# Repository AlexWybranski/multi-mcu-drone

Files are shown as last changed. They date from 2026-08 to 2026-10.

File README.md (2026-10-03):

# multi-mcu-drone

#### Disclaimer
- Due to free profiles of HICPP and CPPCOREGUIDELINES in clang-tidy, this code is supposed to be taken as "HICPP-ish verified"
- **Current State:** Firmware for the STM32 board is tested (all that has been written to this day (**3 Oct 2026**)), work slowed down due to hardware limits - started working on custom pcb

## System overview
This firmware is written primarily in C++. The breakdown of the software modules for each specific board is detailed below:

- [esp32c6-rc](esp32c6-rc/) - Remote control module; handles gamepad input and transmits data wirelessly to the drone via the ESP-NOW protocol.
- [esp32c3-receiver](esp32c3-receiver/) - Receiver module; captures ESP-NOW packets, forwards them to the [stm32f4-main](stm32f4-main/) module via UART, and generates PWM signals for camera servo control.
- [esp32s3-cam](esp32s3-cam/) - Camera module; not implemented at this stage of development.
- [stm32f4-main](stm32f4-main/) - Main flight controller; serves as the brain of the drone, calculating PWM duty cycles for the motors based on UART RX data, accelerometer, and gyroscope inputs.

## Data flow
```mermaid
flowchart LR
%%{init: { 'flowchart': { 'curve': 'stepAfter' }, 'themeCSS': '.edgePath .path { stroke-linejoin: miter; stroke-linecap: square; }' } }%%
    A[Remote Control] 
    B[RECEIVER]
    C[FLIGHT CONTROLLER]
    D[SENSOR]
    E[ESC]
    F[SERVO]
    G[CAM]
    H[HTTP SERVER - VIDEO STREAM]

    A -.->|ESP-NOW| B
    G -.-> H
    subgraph On Drone
    B -->|UART| C
    B -->|PWM| F ===|PHYSICAL CONNECTION|G
    C <-->|SPI| D
    C -->|PWM| E
    end
```

## Credits
- This project uses **[Bluepad32](https://github.com/ricardoquesada/bluepad32)** and its dependency **[BTStack](https://github.com/bluekitchen/btstack)** more about licensing and conditions in [LICENSE-3RD-PARTY](https://github.com/AlexWybranski/multi-mcu-drone/blob/master/LICENSE-3RD-PARTY.md)

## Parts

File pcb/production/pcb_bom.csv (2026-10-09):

Designator | Footprint | Quantity | Value | LCSC Part #
BEC_5V_OUT1 | PinHeader_2x02_P2.54mm_Vertical_SMD | 1 | ~
C3 | CP_EIA-6032-28_Kemet-C_HandSolder | 1 | BEC_50V_20uF
C4 | 1206 | 1 | SER_16V_10uF
C5 | 1206 | 1 | CAM_16V_10uF
C6 | 1206 | 1 | ESP_16V_10uF
C7 | 1206 | 1 | STM_16V_10uF
D1, D2 | D_SOD-123 | 2 | D_Schottky
JST-SH1 | JST_XH_S8B-XH-A_1x08_P2.50mm_Horizontal | 1 | Conn_01x08_Socket
JST-SH2 | JST_XH_S5B-XH-A_1x05_P2.50mm_Horizontal | 1 | Conn_01x05_Socket
R1, R2 | 0805 | 2 | 330
S1 | imu_footprint | 1 | AdaFruit_LSM6DS3_Symbol
U1 | BlackPill AT32F403ACx WeActStudio | 1 | STM32F411CEU6 - BlackPill
U2 | XIAO-ESP32-C6-DIP | 1 | XIAO-ESP32-C6-SMD

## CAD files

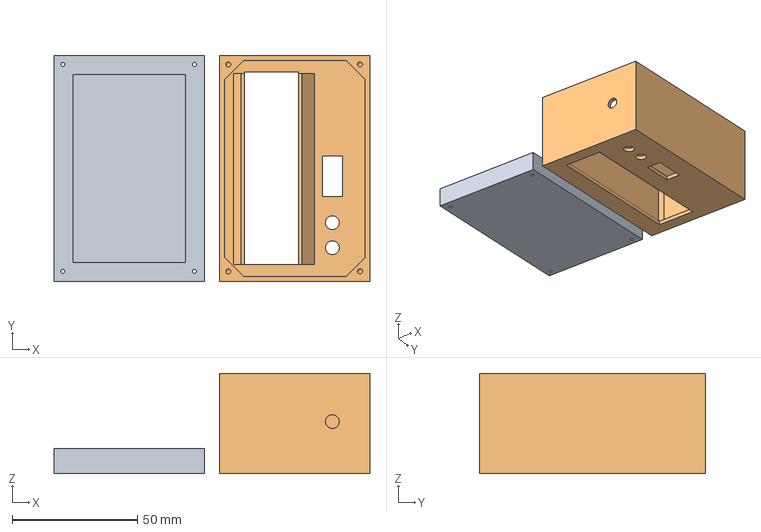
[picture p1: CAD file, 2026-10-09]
rc_case/rc_box.step
126.0 x 90.0 x 40.0 mm

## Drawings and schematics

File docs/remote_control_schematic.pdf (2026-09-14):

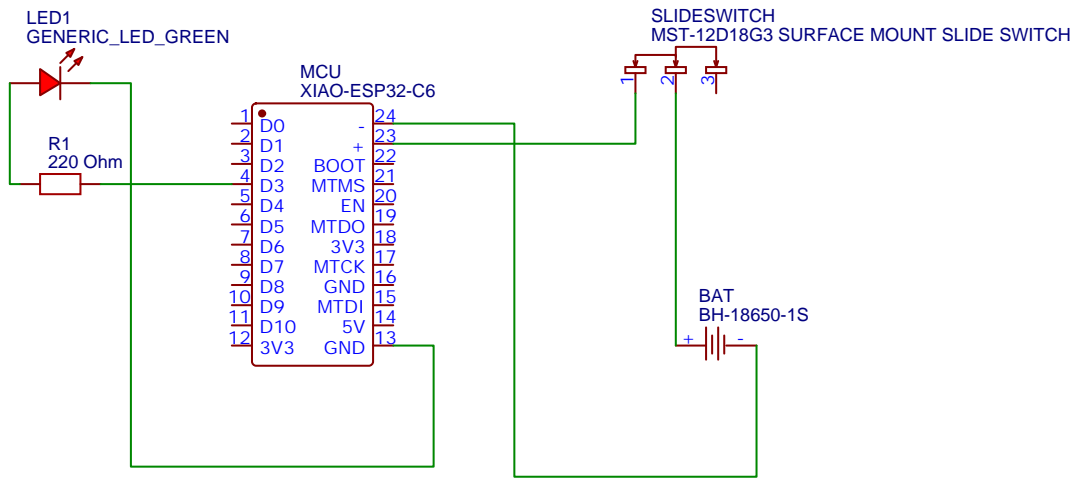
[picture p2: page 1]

SLIDESWITCH
MST-12D18G3 SURFACE MOUNT SLIDE SWITCH

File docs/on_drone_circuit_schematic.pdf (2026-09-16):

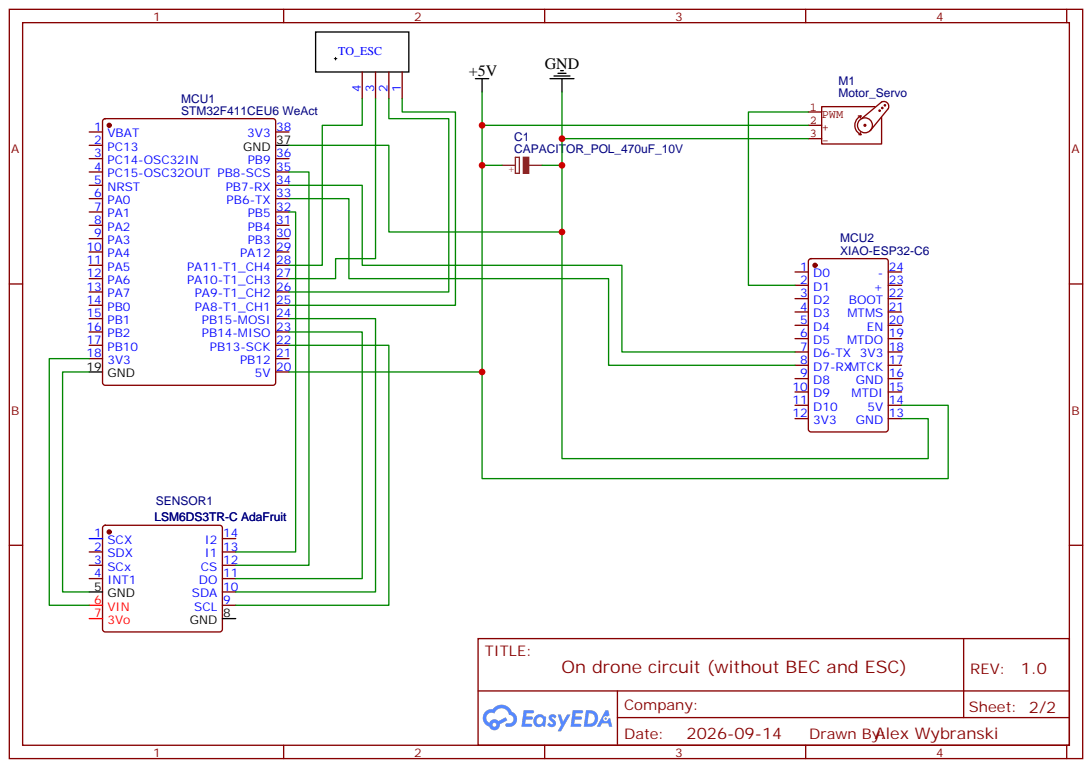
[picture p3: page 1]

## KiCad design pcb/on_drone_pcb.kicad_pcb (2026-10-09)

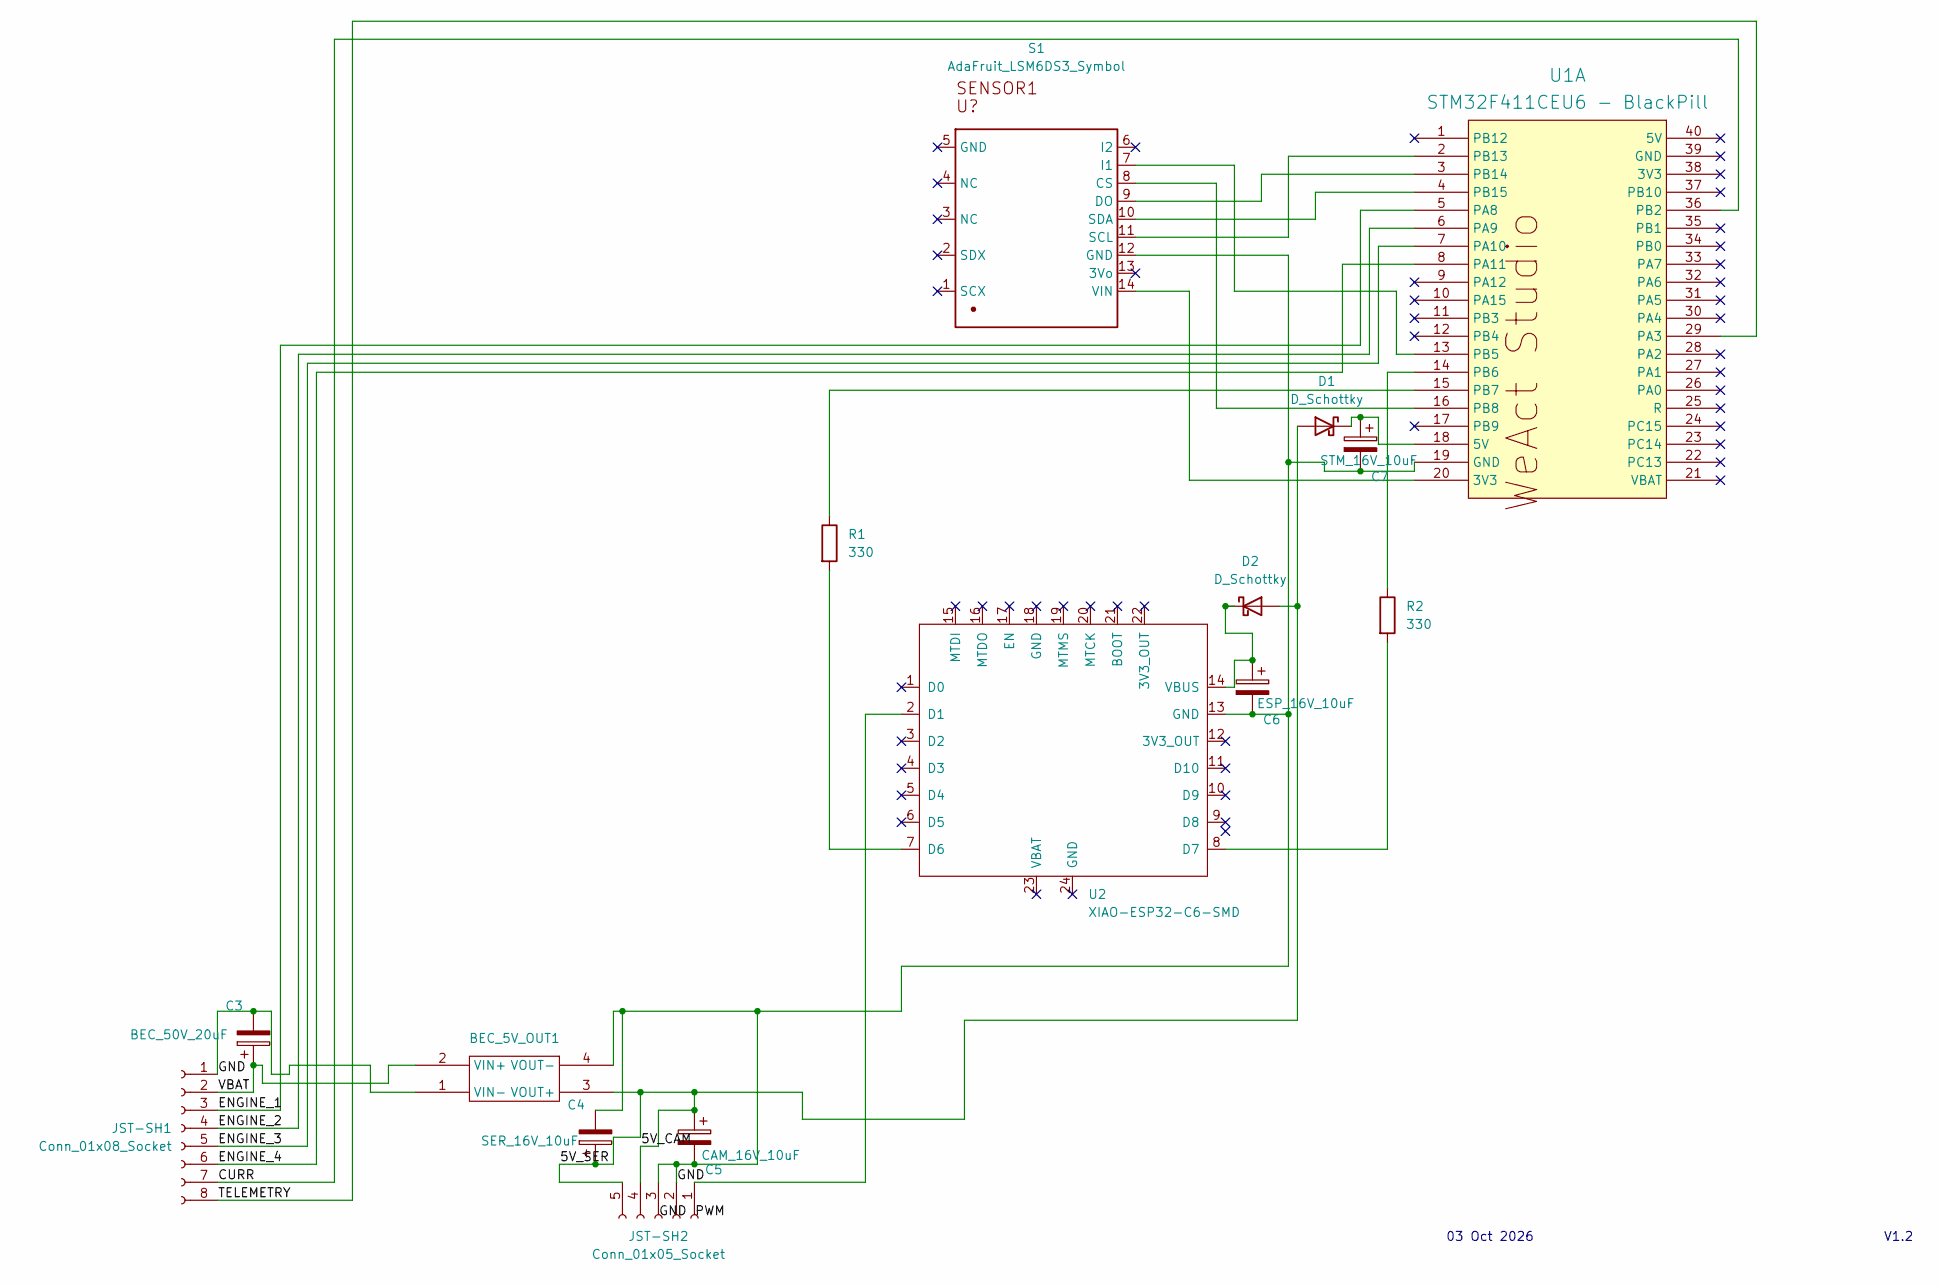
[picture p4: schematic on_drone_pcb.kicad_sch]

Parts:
BEC_5V_OUT1: PinHeader_2x02_P2.54mm_Vertical_SMD
C3: BEC_50V_20uF; CP_EIA-6032-28_Kemet-C_HandSolder
C4: SER_16V_10uF; C_1206_3216Metric_Pad1.33x1.80mm_HandSolder
C5: CAM_16V_10uF; C_1206_3216Metric_Pad1.33x1.80mm_HandSolder
C6: ESP_16V_10uF; C_1206_3216Metric_Pad1.33x1.80mm_HandSolder
C7: STM_16V_10uF; C_1206_3216Metric_Pad1.33x1.80mm_HandSolder
D1, D2: D_Schottky; D_SOD-123
JST-SH1: Conn_01x08_Socket; JST_XH_S8B-XH-A_1x08_P2.50mm_Horizontal
JST-SH2: Conn_01x05_Socket; JST_XH_S5B-XH-A_1x05_P2.50mm_Horizontal
R1, R2: 330; R_0805_2012Metric_Pad1.20x1.40mm_HandSolder
S1: AdaFruit_LSM6DS3_Symbol; imu_footprint
U1: STM32F411CEU6 - BlackPill; BlackPill AT32F403ACx WeActStudio
U2: XIAO-ESP32-C6-SMD; XIAO-ESP32-C6-DIP

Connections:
/5V_CAM: BEC_5V_OUT1.3 (VOUT+), C4.1, C5.1, D1.2 (A), D2.2 (A), JST-SH2.4, JST-SH2.5
/CURR: JST-SH1.7, U1.36 (PB2)
/ENGINE_1: JST-SH1.3, U1.5 (PA8)
/ENGINE_2: JST-SH1.4, U1.6 (PA9)
/ENGINE_3: JST-SH1.5, U1.7 (PA10)
/ENGINE_4: JST-SH1.6, U1.8 (PA11)
/GND: BEC_5V_OUT1.1 (VIN-), BEC_5V_OUT1.4 (VOUT-), C3.2, C4.2, C5.2, C6.2, C7.2, JST-SH1.1, JST-SH2.2, JST-SH2.3, S1.12 (GND), U1.19 (GND), U2.13 (GND)
/TELEMETRY: JST-SH1.8, U1.29 (PA3)
/VBAT: BEC_5V_OUT1.2 (VIN+), C3.1, JST-SH1.2
unnamed: C7.1, D1.1 (K), U1.18 (5V)
unnamed: C6.1, D2.1 (K), U2.14 (VBUS)
unnamed: JST-SH2.1, U2.2 (D1)
unnamed: S1.8 (CS), U1.16 (PB8)
unnamed: S1.9 (DO), U1.3 (PB14)
unnamed: S1.7 (I1), U1.13 (PB5)
unnamed: S1.11 (SCL), U1.2 (PB13)
unnamed: S1.10 (SDA), U1.4 (PB15)
unnamed: S1.14 (VIN), U1.20 (3V3)
unnamed: R2.1, U1.14 (PB6)
unnamed: R1.1, U1.15 (PB7)
unnamed: R1.2, U2.7 (D6)
unnamed: R2.2, U2.8 (D7)

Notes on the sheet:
03 Oct 2026
V1.2

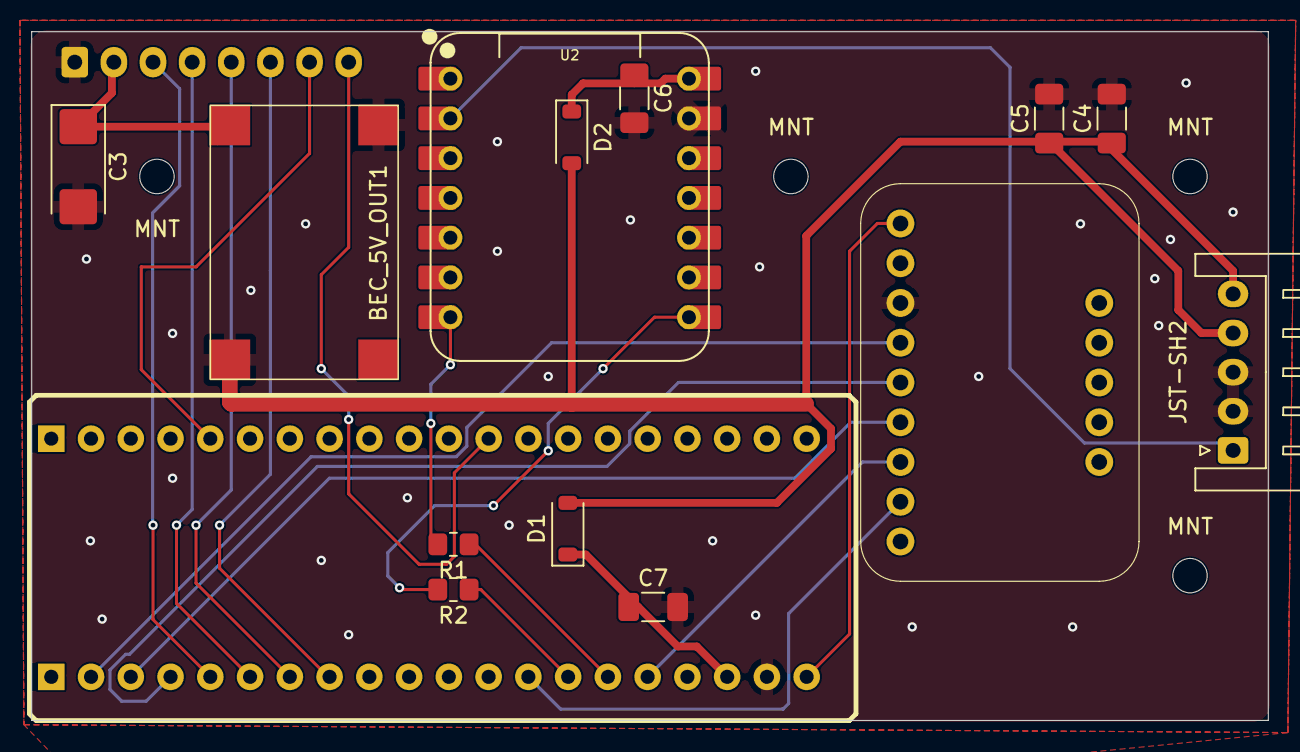
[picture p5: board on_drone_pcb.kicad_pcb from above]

Board: 4 copper layers, 79.0 x 44.0 mm, 19 parts (1 on the bottom side), 22 nets.

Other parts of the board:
MNT: MountingHole_2.2mm_M2
MNT#2, MNT#3, MNT#4: MountingHole_2.2mm_M2

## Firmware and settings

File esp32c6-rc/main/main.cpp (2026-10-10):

// Example file - Public Domain
// Need help? http://bit.ly/bluepad32-help

#include <cstdio>


#include "dronePacket.hpp"
#include "remote.hpp"

extern "C" {
    #include <stdlib.h>
    
    #include <btstack_port_esp32.h>
    #include <btstack_run_loop.h>
    #include <btstack_stdio_esp32.h>
    #include <hci_dump.h>
    #include <hci_dump_embedded_stdout.h>
    #include <uni.h>

    #include "nvs_flash.h"

    #include "sdkconfig.h"

    #include <freertos/FreeRTOS.h>
    #include <freertos/task.h>

    int app_main(void);

    struct uni_platform* get_my_platform(void);
}

constexpr size_t ESP_NOW_TASK_STACK_SIZE = 2048U;
constexpr size_t INDICATOR_TASK_STACK_SIZE = 2048U;
constexpr uint32_t ESP_NOW_TASK_DELAY_MS = 10U;

StackType_t txEspNowTask[ESP_NOW_TASK_STACK_SIZE*4U];
StaticTask_t txEspNowTaskBuffer;
TaskHandle_t txEspNowTaskHandle;

StackType_t indicatorTask[INDICATOR_TASK_STACK_SIZE*4U];
StaticTask_t indicatorTaskBuffer;
TaskHandle_t indicatorTaskHandle;

EventGroupHandle_t indicatorEventGroupHandle;
StaticEventGroup_t indicatorEventGroup;

void txEspNowTaskFunc(void* pvParameters);
void indicatorTaskFunc(void* pvParameters);

// Sanity check
static_assert(
#if defined(CONFIG_BLUEPAD32_PLATFORM_CUSTOM)
    true,
#else
    false,
#endif
    "Must use BLUEPAD32_PLATFORM_CUSTOM in menuconfig!"
);

int app_main(void) {
    esp_err_t ret = nvs_flash_init();
    if (ret == ESP_ERR_NVS_NO_FREE_PAGES || ret == ESP_ERR_NVS_NEW_VERSION_FOUND) {
        ESP_ERROR_CHECK(nvs_flash_erase());
        ret = nvs_flash_init();
    }
    ESP_ERROR_CHECK(ret);

    RemoteControl::initRemoteConnection();

    RemoteControl::initExtAntenna();

    indicatorEventGroupHandle = xEventGroupCreateStatic(&indicatorEventGroup);

    txEspNowTaskHandle = xTaskCreateStaticPinnedToCore
    (
        txEspNowTaskFunc,
        "tx_esp_now_task",
        ESP_NOW_TASK_STACK_SIZE,
        nullptr,
        5,
        txEspNowTask,
        &txEspNowTaskBuffer,
        tskNO_AFFINITY
    );

    // Configure BTstack for ESP32 VHCI Controller
    btstack_init();

    // Must be called before uni_init()
    uni_platform_set_custom(get_my_platform());

    // Init Bluepad32.
    uni_init(0 /* argc */, NULL /* argv */);

    // Does not return.
    btstack_run_loop_execute();

    return 0;
}

void txEspNowTaskFunc(void* pvParameters) {
    using namespace ConstantValues;

    static_cast<void>(pvParameters);

    TickType_t xLastWakeTime;
    const TickType_t xFrequency = pdMS_TO_TICKS(ESP_NOW_TASK_DELAY_MS);

    EventBits_t indicatorBits;

    RemoteControl::initLed();

    xLastWakeTime = xTaskGetTickCount();

    while(1) {
        DroneControlPacket packet = RemoteControl::getAndClearPacket();

        indicatorBits = xEventGroupGetBits(indicatorEventGroupHandle);

        if(indicatorBits & xPadConnected) {
            RemoteControl::sendPacket(&packet);
            gpio_set_level(GREEN_LED, SET_HIGH);
            esp_rom_printf("[PACKET] | Throttle: %u, Pitch: %d, Roll: %d, Buttons: %u, CRC: %X\n", packet.controlData.data.throttle, packet.controlData.data.pitch, packet.controlData.data.roll, packet.controlData.data.buttonControlReg, packet.crcValue);
        } else {
            esp_rom_printf("Pad NOT connected\n");
            gpio_set_level(GREEN_LED, SET_LOW);
        }

        xTaskDelayUntil(&xLastWakeTime, xFrequency);
    }
}

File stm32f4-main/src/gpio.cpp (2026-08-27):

#include "gpio.hpp"

void GpioHandle::setPinMode(GpioHandle::Mode mode, uint32_t pinNum) {
    constexpr uint32_t resetValue = 0b11U;

    auto setValue = static_cast<uint32_t>(mode);
    uint32_t shift = pinNum * 2U;

    m_GPIO->MODER &= ~(resetValue << shift);
    m_GPIO->MODER |= (setValue << shift);
}

void GpioHandle::setPinOutputType(bool isOpenDrain, uint32_t pinNum) {
    constexpr uint32_t resetValue = 0b1U; 
    
    uint32_t shift = pinNum;
    
    m_GPIO->OTYPER &= ~(resetValue << shift);
    
    if(isOpenDrain) {
        uint32_t setValue = 0b1U;
        m_GPIO->OTYPER |= (setValue << shift);
    }
}

void GpioHandle::setPinOutputSpeed(GpioHandle::Speed speed, uint32_t pinNum) {
    constexpr uint32_t resetValue = 0b11U;

    auto setValue = static_cast<uint32_t>(speed);
    uint32_t shift = pinNum * 2U;

    m_GPIO->OSPEEDR &= ~(resetValue << shift);
    m_GPIO->OSPEEDR |= (setValue << shift);
}

void GpioHandle::setPinPullupPulldown(GpioHandle::Pull pull, uint32_t pinNum) {
    constexpr uint32_t resetValue = 0b11U;

    auto setValue = static_cast<uint32_t>(pull);
    uint32_t shift = pinNum * 2U;

    m_GPIO->PUPDR &= ~(resetValue << shift);
    m_GPIO->PUPDR |= (setValue << shift);
}

void GpioHandle::setPinState(bool state, uint32_t pinNum) {
    constexpr uint32_t BSRR_RESET_OFFSET = 16U;

    uint32_t setValue = 0b1U;
    uint32_t shift = pinNum;
    if(!state) {
        shift += BSRR_RESET_OFFSET;
    }
    m_GPIO->BSRR = (setValue << shift);
}

void GpioHandle::setPinAlternateFunction(GpioHandle::Func func, uint32_t pinNum) {
    constexpr uint32_t AFR_PINS_PER_REG = 8U;
    constexpr uint32_t resetValue = 0b1111U;

    auto setValue = static_cast<uint32_t>(func);
    if(pinNum >= AFR_PINS_PER_REG) {
        uint32_t shift = (pinNum % AFR_PINS_PER_REG) * 4U;
        m_GPIO->AFRH &= ~(resetValue << shift);
        m_GPIO->AFRH |= (setValue << shift);
    } else {
        uint32_t shift = pinNum * 4U;
        m_GPIO->AFRL &= ~(resetValue << shift);
        m_GPIO->AFRL |= (setValue << shift);
    }
}

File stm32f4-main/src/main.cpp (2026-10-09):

#include <cstdint>
#include <cstring>

extern "C" {
    #include "FreeRTOS.h"
    #include "task.h"
}

#include "stm32f4.hpp"
#include "rcc.hpp"
#include "dma.hpp"
#include "tim.hpp"
#include "usart.hpp"
#include "spi.hpp"
#include "gpio.hpp"
#include "nvic.hpp"

#include "init.hpp"
#include "rtos_tasks.hpp"

constexpr DmaStreamConfig dma1s3config { //SPI2 RX
    DmaChannel::ch0,
    DmaDirection::per_to_mem,
    DmaPriority::medium,
    DmaMode::single
};

constexpr DmaStreamConfig dma1s4config { //SPI2 TX
    DmaChannel::ch0,
    DmaDirection::mem_to_per,
    DmaPriority::low,
    DmaMode::single
};

constexpr DmaStreamConfig dma2s5config { //UART1 RX
    DmaChannel::ch4,
    DmaDirection::per_to_mem,
    DmaPriority::medium,
    DmaMode::double_buffer
};

//Pointers to objects are needed for IRQ_table, they have to be global and non-const because they are being initialized in main function
//NOLINTBEGIN(cppcoreguidelines-avoid-non-const-global-variables)
namespace IRQ_Config {
    using IRQFunc = void(*)(void);

    inline DmaStreamHandle<PeripheralBaseAddr::DMA1_BASEADDR, DMA_SETUP::STREAM_3, dma1s3config, DMA_SETUP::SPI_NDTR_VAL>* volatile dma1s3 = nullptr;
    inline DmaStreamHandle<PeripheralBaseAddr::DMA2_BASEADDR, DMA_SETUP::STREAM_5, dma2s5config, DMA_SETUP::UART_NDTR_VAL>* volatile dma2s5 = nullptr;
    inline UsartHandle* uart1 = nullptr;
}
//NOLINTEND(cppcoreguidelines-avoid-non-const-global-variables)

// extern "C" block excluded from linter, due to freertos function breaking the rules
//NOLINTBEGIN(cppcoreguidelines-avoid-magic-numbers, cppcoreguidelines-pro-bounds-array-to-pointer-decay,hicpp-no-array-decay)
extern "C" {
    void _init(void) {}
    void vApplicationGetIdleTaskMemory( StaticTask_t **ppxIdleTaskTCBBuffer,
                                        StackType_t **ppxIdleTaskStackBuffer,
                                        uint32_t *pulIdleTaskStackSize )
    {
        static StaticTask_t xIdleTaskTCB;
        static StackType_t uxIdleTaskStack[128];

        *ppxIdleTaskTCBBuffer = &xIdleTaskTCB;
        *ppxIdleTaskStackBuffer = uxIdleTaskStack;
        *pulIdleTaskStackSize = 128;
    }

    void DMA1_Stream3_IRQHandler() { //SPI_RX
        if (IRQ_Config::dma1s3 != nullptr) {
            IRQ_Config::dma1s3->handleIRQ();
        }
    }

    void DMA2_Stream5_IRQHandler() { //UART_RX
        if (IRQ_Config::dma2s5 != nullptr) {
            IRQ_Config::dma2s5->handleIRQ();
        }
    }

    void USART1_IRQHandler() {
        if (IRQ_Config::uart1 != nullptr) {
            IRQ_Config::uart1->handleIRQ();
        }
    }
} //NOLINTEND(cppcoreguidelines-avoid-magic-numbers, cppcoreguidelines-pro-bounds-array-to-pointer-decay,hicpp-no-array-decay)

int main() {
    static RccHandle rcc(PeripheralBaseAddr::RCC_BASEADDR);
    
    static GpioHandle gpioA(PeripheralBaseAddr::GPIOA_BASEADDR);
    static GpioHandle gpioB(PeripheralBaseAddr::GPIOB_BASEADDR);

    static DmaStreamHandle<PeripheralBaseAddr::DMA1_BASEADDR, DMA_SETUP::STREAM_3, dma1s3config, DMA_SETUP::SPI_NDTR_VAL> dma1s3_spirx; //SPI_RX
    static DmaStreamHandle<PeripheralBaseAddr::DMA1_BASEADDR, DMA_SETUP::STREAM_4, dma1s4config, DMA_SETUP::SPI_NDTR_VAL> dma1s4_spitx; //SPI_TX
    static DmaStreamHandle<PeripheralBaseAddr::DMA2_BASEADDR, DMA_SETUP::STREAM_5, dma2s5config, DMA_SETUP::UART_NDTR_VAL> dma2s5_uartrx; //UART_RX

    static SpiHandle spi2(PeripheralBaseAddr::SPI2_BASEADDR, &gpioB);
    static UsartHandle uart1(PeripheralBaseAddr::USART1_BASEADDR);
    
    static Tim1Handle tim1(PeripheralBaseAddr::TIM1_BASEADDR);

    static Nvic nvic(PeripheralBaseAddr::NVIC_BASEADDR);

    IRQ_Config::uart1 = &uart1;
    IRQ_Config::dma1s3 = &dma1s3_spirx;
    IRQ_Config::dma2s5 = &dma2s5_uartrx;

    initClocks(rcc);
    initGpio(gpioA, gpioB);

    tim1.init();
    
    static imuTaskContext imuTaskCtx {
        []() {
            dma1s4_spitx.disableStream();
            dma1s3_spirx.disableStream();
            
            dma1s3_spirx.enableStream();
            dma1s4_spitx.enableStream();
        },
        &spi2
    };

    static enginesTaskContext enginesTaskCtx {
        &tim1
    };

    initTasks(&imuTaskCtx, &enginesTaskCtx);
    
    TaskHandle_t receiverTaskPtr = getReceiverTaskHandle();
    TaskHandle_t imuTaskPtr = getImuTaskHandle();
    
    dma1s3_spirx.init(spi2.getDataRegAddr(), imuTaskPtr);
    dma1s4_spitx.init(spi2.getDataRegAddr(), nullptr);
    dma2s5_uartrx.init(uart1.getDataRegAddr(), receiverTaskPtr);
    
    spi2.init(GPIOB_PINS::SPI2_SCS);
    uart1.init();

    initIRQs(nvic);
    
    vTaskStartScheduler();

    while (1) {
    
    }

    return 0;
}

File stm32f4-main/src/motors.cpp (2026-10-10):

#include "motors.hpp"

MotorPWMs MotorMixer::mixMotors(const DroneControlData& data) {
    using namespace MOTOR_SETUP;

    MotorPWMs motors;

    int16_t l_throttle = static_cast<int16_t>(data.throttle << 1);
    int16_t l_yaw;

    if (data.buttonControlReg & ControlRegister::YAW_LEFT) {
        l_yaw = YAW_LEFT_STEP;
    } else if (data.buttonControlReg & ControlRegister::YAW_RIGHT) {
        l_yaw = YAW_RIGHT_STEP;
    } else {
        l_yaw = 0;
    }

    motors.motorRigFro_1 = static_cast<int16_t>(l_throttle - data.roll + data.pitch + l_yaw); //RF
    motors.motorLefRea_2 = static_cast<int16_t>(l_throttle + data.roll - data.pitch + l_yaw); //LR
    motors.motorLefFro_3 = static_cast<int16_t>(l_throttle + data.roll + data.pitch - l_yaw); //LF
    motors.motorRigRea_4 = static_cast<int16_t>(l_throttle - data.roll - data.pitch - l_yaw); //RR

    motors.motorRigFro_1 = clamp(motors.motorRigFro_1);
    motors.motorLefRea_2 = clamp(motors.motorLefRea_2);
    motors.motorLefFro_3 = clamp(motors.motorLefFro_3);
    motors.motorRigRea_4 = clamp(motors.motorRigRea_4);

    return motors;
}

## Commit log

2026-08-31 [#2] Implemented RCC Class with method for setting sys clock on 48MHz, started writing class for TIM/PWM control
2026-08-31 [#3] Created SPI init method
2026-08-31 [#4] Added interrupt flags to SPI::init method, added rcc methods to enable peripherals' clocks
2026-09-02 Integrated bluepad32 library with cpp RemoteControl class, started writing RC module, inputs from gamepad are saved to packet correctly
    [main.cpp, remote.cpp]
2026-09-03 [#11] Added receiver class [esp32c3-receiver], paired rc with receiver - packets are transferring correctly via ESP-NOW
    [partitions.csv]
2026-09-04 [#12] Added UART communication for esp32c3-receiver, added functions to start esp-now transmit only if gamepad is ready, added function to communicate that gamepad has disconnected for esp32c6-rc
2026-09-05 [#13] Added functions to initialize usart and dma in stm32f4-main
2026-09-06 [#14] Added SPI methods to read, write, and handle interrupt, did cleanup in code (NOLINTS where was justified and in CMakeLists.txt)
2026-09-08 [#17] Added servo support for esp32c3-receiver
2026-09-08 [#19] Added support for holding buttons in esp32c6-rc
2026-09-10 [#22] Clean up in code (nolints, renamed SPI-constants namespace to clarify its purpose, made class objects static (direct them to .bss section)), prepared main to write freertos tasks
2026-09-11 [#23] Created blueprints for tasks, fixes dma irq's compilation error
    [main.cpp, spi.cpp]
2026-09-14 [#24] Created electronic schematic for remote control module (esp32c6-rc)
2026-09-16 [#25] Created schematic for on drone circuit, edited readme, added dummy file to show esp32s3-cam folder in repo
2026-09-18 [#26] Added led indicator to esp32c6-rc, implemented event group instead of private field isPadReady
2026-09-19 [#27] Added DMA IRQ and started writing receiverTask
2026-09-20 [#28] Added CRC calculation in receiverTask in stm32f4-main
2026-09-20 [#29] Tested uart dma and spi register configurations, registers are initialized correctly
    [dma.hpp, main.cpp, spi.cpp]
2026-09-21 [#30] Tested uart and dma, adjusted CRC calculation on esp32c6-rc, fixed nvic methods, fixed vector table order, tested data flow between mcus, packets are correctly sent from rc through receiver to 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
    [main.cpp, receiver.cpp, receiver.hpp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]
2026-09-22 [#31] Refactorized main.cpp, added dedicated init.cpp and rtos_tasks.cpp for peripherals and rtos tasks, minor fixes in nvic.hpp, stm32f4.hpp, crc.cpp, dma.hpp. Tested changes on hardware
    [dma.hpp, init.cpp, main.cpp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]
2026-09-24 [#34] Added table of interrupt handlers, rewritten dma class to not be singleton and be responsible for 1 stream, got rid of previous classes' static instances
2026-09-25 [#35] created prototypes for spi communication (polling and dma versions), needs testing
2026-09-27 [#36] SPI with DMA tested, working stable at 750KHz, hardware can't hold more due to long wires, hardware resoldering needed
2026-10-03 [#36] Tested SPI and UART on prototype hardware, spi 750kHz still works stable, did clean-up in code (got rid of dead-code and redundant constexpr values
2026-10-04 [#37] Added driver for advanced timer, needs testing
2026-10-04 [#38] Fixed and tested timer PWM generation
    [main.cpp, rtos_tasks.cpp, tim.cpp]
2026-10-05 [#39] Created prototype for motor mixer and atomic exchange of data between enginesTask and receiverTask
2026-10-09 [#40] Modified DroneControlPacket, adjusted rc and receiver for new packet structure, added pcb files, added 3d model of remote control module case
    [on_drone_pcb.kicad_pcb, on_drone_pcb.kicad_sch, pcb_bom.csv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]
2026-10-10 [#41] Fixed and adjusted motor mixer and adjusted receiverTask for stmf411-main, switched esp32c6-rc to work with external antenna
    [main.cpp, motors.cpp, remote.cpp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]
2026-10-10 [#42] Added prototype of failsafeTask, added global variable to store data read from imu sensor, added critical sections to write and read imu sensor data
    [rtos_tasks.cpp]
2026-10-17 [#43] Added prototype of streaming from camera to http server in esp32s3-cam
2026-10-20 [#45] Added normalizing data from imu and calculating real angles via complementary filter, deleted imuTask, now flightControlTask (former enginesTask) handles imu, spotted bug in failsafe task (is t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
2026-10-21 [#46] Fixed failsafeTask, added g_hasLanded flag (prototype), tested failsafeTask
2026-10-25 [#48] Added pid algorithm, changes in motors.cpp and tim.cpp
2026-10-26 [#49] refactorized dma driver template to take only config structure, moved all info to that struct
2026-10-26 [#50] tested and added little fixed to PID
2026-10-28 [#53] Added controlling battery level in esp32c6-rc
2026-10-29 [#54] Changed duty values in esp32c6-receiver
2026-11-02 [#55] Modified MotorPWMs struct and MotorMixer::mixMotors logic to match physical connections on ESC
2026-11-04 [#57] Switched esp32c6-receiver to work with external antenna
